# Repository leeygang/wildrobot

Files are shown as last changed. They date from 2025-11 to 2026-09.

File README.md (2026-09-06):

# WildRobot

A humanoid robot locomotion project centered on MuJoCo/JAX training, with an
industry-style RL deployment path as the current mainline for WildRobot.

Current repo reality:
- the repo is pivoting from standing-first PPO exploration toward a
  locomotion-first `v0.19.x` platform
- the deployed runtime artifact remains a **learned policy**
- reduced-order references and IK are moving into top-level `control/` as
  nominal-motion and training-support infrastructure
- `training/` remains the home for RL, eval, export, and locomotion curricula
- `runtime/` remains the hardware-facing layer and will absorb locomotion
  policy running plus shared logging
- `tools/` becomes the explicit home for SysID, replay, and sim2real analysis
- OCS2 / `wb_humanoid_mpc` and URDF migration remain long-term reference
  directions, not the active implementation target for current hardware

Architecture references:
- [docs/system_architecture.md](docs/system_architecture.md)
- [training/docs/walking_training.md](training/docs/walking_training.md) - active locomotion roadmap
- [training/docs/toddlerbot_direct_ppo.md](training/docs/toddlerbot_direct_ppo.md) - `v0.21.0-tb1` direct-PPO parity baseline
- [training/docs/ToddlerBot_direction.md](training/docs/ToddlerBot_direction.md) - ToddlerBot-style pivot rationale
- [training/docs/standing_training.md](training/docs/standing_training.md) - standing branch history and regression gates
- [training/docs/footstep_planner_rl_adoption.md](training/docs/footstep_planner_rl_adoption.md)
- [training/docs/ocs2_humanoid_mpc_adoption.md](training/docs/ocs2_humanoid_mpc_adoption.md)

## Project Structure

Mainline platform split after the locomotion pivot:

```
wildrobot/
├── README.md                           # This file
├── AGENTS.md                           # Agent guidelines
├── CLAUDE.md                           # Claude AI guidelines
├── pyproject.toml                      # Python package configuration (uv)
├── docs/                               # Repo-level architecture and process docs
│   ├── system_architecture.md          # Mainline system architecture
│   ├── URDF_migration_plan.md          # Deferred URDF migration notes
│   ├── e2e_training_to_sim2real.md     # Sim2real flow notes
│   └── sim2real_policy_contract.md     # Policy contract docs
│
├── assets/                             # Digital twin and robot model files
│   ├── v2/                             # Active WildRobot asset variant
│   │   ├── wildrobot.xml               # Main MuJoCo robot model
│   │   ├── mujoco_robot_config.json    # Generated robot metadata
│   │   ├── scene_flat_terrain.xml      # Training scene
│   │   ├── sensors.xml                 # Sensor definitions
│   │   └── assets/                     # Generated Mesh files (STL)
│   ├── post_process.py                 # Post-process during model generation
│   ├── update_xml.sh                   # Regenerate XML/config from Onshape
│   └── robot_config.py                 # Robot config helpers
│
├── control/                            # Reduced-order references, IK, adapters, reusable non-PPO helpers
│   ├── interfaces.py                   # Shared controller / reference-side interfaces
│   ├── robot_model/                    # Robot-model interfaces and conventions
│   ├── reduced_model/                  # LIPM / DCM / ALIP-style helpers
│   ├── references/                     # Walking reference generators (Milestone 2+)
│   ├── kinematics/                     # Leg IK and nominal-motion utilities (Milestone 2+)
│   ├── locomotion/                     # Unified walking controller (v0.19.5)
│   │   ├── __init__.py
│   │   ├── walking_controller.py       # Orchestrator: ref → IK → [optional residual] → ctrl
│   │   │                               #   mode: nominal_only (v0.19.4) | residual_ppo (v0.19.5)
│   │   └── nominal_ik_adapter.py       # IK adapter: task-space targets → joint angles (NumPy)
│   ├── adapters/                       # Reference -> joint-target adapters
│   ├── execution/                      # Servo-friendly execution / tracking layer
│   └── mpc/                            # Reserved for future advanced planner work
│
├── training/                           # RL, eval, export, locomotion curricula
│   ├── train.py                        # Training entry point
│   ├── CHANGELOG.md                    # Training version history (v0.20.1+)
│   ├── CHANGELOG.archive.md            # Training version history (pre-v0.20.1)
│   │
│   ├── cal/                            # v0.11.0: Control Abstraction Layer (CAL)
│   │   ├── __init__.py                 # Export CAL, specs, types
│   │   ├── cal.py                      # ControlAbstractionLayer class
│   │   ├── specs.py                    # JointSpec, ActuatorSpec, Pose3D, Velocity3D
│   │   ├── types.py                    # ActuatorType, VelocityProfile, CoordinateFrame
│   │   └── cal.md                      # CAL documentation
│   │
│   ├── configs/                        # Configuration system
│   │   ├── __init__.py
│   │   ├── training_config.py          # Training config schema
│   │   ├── training_runtime_config.py  # Runtime config
│   │   ├── ppo_walking_v0201_smoke.yaml # v0.20.1 walking smoke
│   │   └── ppo_standing.yaml           # Standing task config
│   │
│   ├── docs/                           # Training documentation
│   │   ├── walking_training.md         # Active locomotion roadmap
│   │   ├── ToddlerBot_direction.md     # ToddlerBot-style pivot note
│   │   ├── standing_training.md        # Standing branch history / regression gates
│   │   ├── footstep_planner_rl_adoption.md # RL-first + optional teacher plan
│   │   ├── ocs2_humanoid_mpc_adoption.md # Deferred OCS2 / humanoid MPC notes
│   │   └── archive/                    # Archived / superseded training docs
│   │       └── learn_first_plan.md     # Historical walking-first roadmap
│   │
│   ├── envs/                           # Environment implementation
│   │   ├── wildrobot_env.py            # Main JAX environment
│   │   ├── env_info.py                 # Typed info + metrics schema
│   │   └── disturbance.py              # Push disturbance utilities
│   │
│   ├── exports/                        # Export utilities
│   │   ├── export_onnx.py              # Checkpoint → ONNX
│   │   ├── export_policy_bundle.py     # Bundle writer (library)
│   │   └── export_policy_bundle_cli.py # Bundle export CLI
│   │
│   ├── eval/                           # Evaluation tools
│   │   ├── eval_policy.py              # Headless evaluation
│   │   ├── eval_ladder_v0170.py        # Standing fixed ladder
│   │   └── visualize_policy.py         # MuJoCo viewer playback
│   │
│   ├── scripts/                        # Analysis scripts
│   │
│   ├── sim_adapter/                    # Sim signal extraction
│   │   ├── mjx_signals.py              # MJX Signals adapter
│   │   └── mujoco_signals.py           # Native MuJoCo Signals adapter
│   │
│   ├── core/                           # Training infrastructure (loop/rollout/metrics)
│   │   ├── __init__.py
│   │   ├── training_loop.py            # Main training loop
│   │   ├── rollout.py                  # Rollout collection
│   │   ├── checkpoint.py               # Checkpoint save/load
│   │   ├── metrics_registry.py         # Metrics tracking
│   │   └── experiment_tracking.py      # W&B integration
│   │
│   ├── algos/                          # Algorithm components
│   │   └── ppo/                         # PPO-specific core
│   │       ├── __init__.py
│   │       └── ppo_core.py              # PPO networks/losses/GAE
│   │
│   ├── tests/                          # All tests (consolidated)
│   │   ├── TEST_STRATEGY.md            # Comprehensive test strategy
│   │   ├── conftest.py                 # Shared test fixtures
│   │   ├── robot_schema.py             # Schema validation utilities
│   │   ├── run_validation.py           # Validation runner
│   │   │
│   │   │ # Physics & Environment Tests
│   │   ├── test_physics_validation.py  # Physics correctness
│   │   ├── test_reward_components.py   # Reward computation
│   │   ├── test_foot_contacts.py       # Contact force validation
│   │   ├── test_env_info_schema.py     # Environment info schema
│   │   │
│   │   │ # Training Component Tests
│   │   ├── test_training_components.py # Training infrastructure
│   │   ├── test_trainer_invariance.py  # Training invariance
│   │   ├── test_ppo_core.py            # PPO algorithm tests
│   │   │
│   │   │ # Math Utility Tests
│   │   ├── test_quat_edges.py          # Quaternion edge cases
│   │   ├── test_quat_normalize.py      # Quaternion normalization
│   │   │
│   │   │ # Environment State Tests
│   │   ├── envs/                       # JAX environment tests
│   │   │   ├── test_jax_env_fns.py
│   │   │   ├── test_jax_equiv_small.py
│   │   │   ├── test_jax_equiv_expanded.py
│   │   │   ├── test_jax_fullstate_small.py
│   │   │   ├── test_jax_contact_equiv.py
│   │   │   └── test_termination_checks.py
│   │   │
│   │   └── debug_contact_forces.ipynb  # Contact force debugging
│   │
│   ├── scripts/                        # Debug & diagnostic scripts
│   │   ├── diagnose_torque.py
│   │   ├── gait_diagnostic.py
│   │   └── test_actuator_range.py
│   │
│   ├── checkpoints/                    # Saved model checkpoints
│   │   └── wildrobot_ppo_*/            # Training run checkpoints
│   │
│   └── wandb/                          # W&B experiment logs
│
├── policy_contract/                    # Shared sim2real contract (spec + JAX/NumPy implementations)
│   ├── spec.py                         # PolicySpec schema + validators + bundle loader
│   ├── spec_builder.py                 # Canonical PolicySpec builder (used by training + export + eval)
│   ├── jax/                            # JAX backend (training)
│   └── numpy/                          # NumPy backend (runtime + tooling)
│
├── runtime/                            # Hardware runtime and shared execution logs
│   ├── README.md                       # Runtime install + run instructions
│   ├── configs/                        # Runtime JSON config templates (hardware calibration source of truth)
│   │   ├── hardware_config.json        # Canonical calibrated hardware config
│   │   ├── walking_v0194.json          # Nominal-only walking deploy config (v0.19.4)
│   │   └── walking_v0195.json          # Residual PPO walking deploy config (v0.19.5)
│   ├── scripts/                        # Calibration tools (IMU/servo/footswitch)
│   └── wr_runtime/                     # Importable runtime package + CLIs
│       ├── control/
│       │   ├── run_policy.py           # Standing/general policy runner
│       │   ├── run_walking.py          # Walking controller entry point (v0.19.5)
│       │   ├── loc_ref_runtime.py      # Walking ref v1 runtime wrapper
│       │   └── loc_ref_runtime_v2.py   # Walking ref v2 runtime wrapper (v0.19.5)
│       └── locomotion/                 # Planned locomotion runner / command / log schema layer
│
├── tools/                              # Sim2real and platform tooling (Milestone 0+)
│   ├── sysid/                          # Actuator characterization and fitting tools
│   └── sim2real_eval/                  # Replay, comparison, and regression plotting tools
│
├── mujoco-brax/                        # Legacy mujoco brax training version.(reference only not used)
│   ├── README.md
│   ├── common/                         # Shared utilities
│   ├── playground/                     # Experimental code
│   └── runtime/                        # Runtime utilities
│
├── isaac/                              # IsaacLab integration (WIP, not used)
│   ├── isaac_lab_strategy.md           # Integration strategy
│   ├── assets/                         # USD assets
│   └── scripts/                        # Conversion scripts
│
└── scripts/                            # Project-level scripts
    ├── scp_to_remote.sh                # Upload to remote server
    └── scp_from_remote.sh              # Download from remote server
```

## Architecture Split

Use this rule of thumb:

- `assets/` owns the digital twin
  - MJCF / scene files
  - generated robot metadata
  - sensor and asset definitions

- `control/` owns locomotion priors and reusable nominal-motion logic
  - reduced-order models
  - reference generation
  - IK and adapters
  - execution / tracking helpers
  - optional future planning experiments

- `training/` owns RL and evaluation
  - locomotion and standing experiments
  - training loops
  - fixed eval ladders
  - reward / curriculum work
  - logging and checkpointing
  - exportable learned policies
  - wrappers that call into `control/`

- `runtime/` owns hardware execution
  - runtime configs
  - policy runners
  - hardware-facing calibration scripts
  - shared runtime log schema

- `tools/` owns sim2real engineering support
  - SysID capture / fitting
  - replay and trace comparison
  - calibration and regression utilities

`training/` may depend on `control/`.  
`control/` should not depend on PPO-specific training code.

## Getting Started

### Prerequisites

- Python 3.11+
- [uv](https://github.com/astral-sh/uv) package manager
- MuJoCo 3.x
- JAX with GPU support (optional but recommended)

### Installation

```bash
# Clone the repository
git clone <your-repo-url>
cd wildrobot

# Install dependencies with uv
uv sync

# Or install in development mode
uv pip install -e .
```

### Running Tests

All tests are consolidated under `training/tests/`:

```bash
# Run all tests
uv run pytest training/tests -v

# Run specific test categories
uv run pytest training/tests/test_physics_validation.py -v  # Physics tests
uv run pytest training/tests/test_reward_components.py -v   # Reward tests
uv run pytest training/tests/test_ppo_core.py -v            # PPO tests
uv run pytest training/tests/envs/ -v                        # Environment tests

# Run with coverage
uv run pytest training/tests --cov=training --cov-report=html
```

## Training

The commands below are for the PPO training stack in `training/`.

For CAD/mass/inertia updates that keep a compatible actor shape, use the
actor-only fine-tuning workflow in
[`training/docs/morphology_finetune.md`](training/docs/morphology_finetune.md).
It deliberately starts a fresh critic and optimizer instead of resuming stale
value/optimizer state.

### Walking Task

```bash
# v0.20.1 walking smoke
uv run python training/train.py --config training/configs/ppo_walking_v0201_smoke.yaml

# Resume from checkpoint (file path, not directory)
uv run python training/train.py \
  --config training/configs/ppo_walking_v0201_smoke.yaml \
  --resume training/checkpoints/<job_dir>/checkpoint_<iter>_<steps>.pkl
```

### Configuration

Training is configured via YAML files in `training/configs/`:

- `ppo_walking_v0201_smoke.yaml` - v0.20.1 walking smoke (offline ZMP prior + bounded residual)
- `ppo_standing.yaml` - Standing balance task

Key configuration options:

```yaml
# Training parameters
training:
  num_envs: 4096
  rollout_steps: 32
  num_iterations: 1000
  learning_rate: 3e-4

# Reward weights
reward:
  velocity_tracking: 1.0
  orientation: 0.5
  action_smoothness: 0.1
```

### Monitoring Training

Training progress is logged to [Weights & Biases](https://wandb.ai/):

```bash
# View live training metrics
wandb login
# Then check your W&B dashboard
```

## Visualization

```bash
# Visualize trained policy
uv run python training/eval/visualize_policy.py \
  --checkpoint training/checkpoints/<checkpoint_dir>
```

## Project Goals

- Develop a bipedal humanoid robot capable of robust locomotion
- Achieve stable walking across flat and rough terrains
- Validate simulation accuracy with comprehensive test suite

## Key Features

- **JAX/MJX Acceleration**: Fast parallel simulation with JAX
- **Prior-Guided PPO**: Offline ZMP reference + bounded residual policy
- **Comprehensive Testing**: 10-layer test strategy from schema contracts to integration
- **Schema Contracts**: Prevents silent breakage from XML changes
- **W&B Integration**: Full experiment tracking and visualization

## Development Workflow

1. **Robot Model**: Define/update robot in `assets/v1/wildrobot.xml` (default) or `assets/v2/wildrobot.xml` (variant)
2. **Configuration**: Adjust training params in `training/configs/`
3. **Training**: Run experiments with `training/train.py`
4. **Testing**: Validate with `pytest training/tests/`
5. **Analysis**: Review metrics in W&B dashboard

## Documentation

Detailed documentation is available in `training/docs/`:

- [Walking Training Plan](training/docs/walking_training.md) - v0.20.x locomotion roadmap
- [Reference Design](training/docs/reference_design.md) - Offline ZMP prior + bounded residual contract
- [Test Strategy](training/tests/test_plan.md) - Comprehensive test plan
- [E2E Runbook](docs/e2e_training_to_sim2real.md) - Train → eval → export → sim2real

## Contributing

Feel free to submit issues and enhancement requests!

## License

[Your License Here]

## Acknowledgments

- MuJoCo and MJX teams at DeepMind
- JAX team at Google
- [Any other acknowledgments]

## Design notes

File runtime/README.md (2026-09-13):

# WildRobot Runtime

Lightweight hardware runtime for running WildRobot ONNX policies on Raspberry Ubuntu.

Implementation lives in `runtime/wr_runtime/` (this is what the installed CLIs use).

Breaking change: the legacy modules under `runtime/control`, `runtime/inference`, `runtime/utils`, and `runtime/validation`
were removed. Use the console scripts (`wildrobot-run-policy`, `wildrobot-validate-bundle`, ...) or import from `wr_runtime.*`.

## Latest contract (v0.21.0, `wr_obs_v8_cmd3d`)

The current walking policy is a **home-base residual** policy (smoke9): the
network outputs a residual that is scaled per-joint and added to the walking
base pose, NOT a direct midpoint-range target.  By default the walking base is
the physical home pose; a bundle can carry small walking-only joint offsets
without changing standing/home calibration.  The runtime composes the target as

```
filtered = postprocess(raw_action)                    # action_filter_alpha=0 -> identity
applied   = previous filtered action                  # action_delay_steps=1
delta     = clip(applied, -1, 1) * residual_scale_per_joint
walking_base_q = home_q_rad + residual_base_offset_per_actuator
target_q  = clip(walking_base_q + delta, joint_min, joint_max)
```

These quantities (residual base/scale/offsets, action delay/filter, the 3D
`(vx, vy, wz)` command, and the gait phase clock) are NOT in `policy_spec.json`.
They are frozen at export time into **`runtime_policy_config.json`** inside the
bundle (see `training/exports/runtime_metadata.py`).  The runner refuses to fall
back to the generic `pos_target_rad_v1` midpoint mapping for a v8 bundle, and
fails loudly for unsupported obs layouts or residual bases.

Legacy `action_scale_rad` in hardware configuration is **ignored** for the
v8 contract — per-joint residual scales come from `runtime_policy_config.json`.

## Install (on robot)

From the `wildrobot/` repo root:

```bash
cd runtime

# Create/update the runtime virtualenv from uv.lock
uv sync
```

Alternative (explicit editable install):
```bash
cd runtime
uv venv
uv pip install -e .
```

Why editable (`-e`) matters: it installs the `wildrobot-*` console scripts while still running
your live checked-out source. If you `git pull` frequently on the device, you usually do *not*
need to reinstall (unless dependencies changed — then rerun `uv sync`).

## Configuration

`runtime/configs/hardware_config.json` is the hardware source of truth. Policy
bundles do not contain hardware configuration. `--hardware-config` remains an
explicit override, and `--runtime-config` remains its legacy alias.

Minimal example:

```json
{
  "robot_config_path": "./mujoco_robot_config.json",
  "servo_controller": {
    "type": "hiwonder_ttl_bus",
    "baudrate": 115200,
    "boards": [
      { "name": "left_leg_board", "port": "/dev/serial/by-id/usb-board-left", "servo_ids": [1, 2, 3, 4] },
      { "name": "right_leg_board", "port": "/dev/serial/by-id/usb-board-right", "servo_ids": [5, 6, 7, 8] },
      { "name": "upper_body_board", "port": "/dev/serial/by-id/usb-board-upper", "servo_ids": [40] }
    ],
    "servos": {
      "left_hip_pitch":  { "id": 1, "servo_offset_unit": 0, "motor_unit_direction": 1, "joint_angle_at_servo_center_deg": 0 },
      "left_hip_roll":   { "id": 2, "servo_offset_unit": 0, "motor_unit_direction": 1, "joint_angle_at_servo_center_deg": 0 },
      "left_knee_pitch": { "id": 3, "servo_offset_unit": 0, "motor_unit_direction": 1, "joint_angle_at_servo_center_deg": 0 },
      "left_ankle_pitch": { "id": 4, "servo_offset_unit": 0, "motor_unit_direction": 1, "joint_angle_at_servo_center_deg": 0 },
      "right_hip_pitch": { "id": 5, "servo_offset_unit": 0, "motor_unit_direction": 1, "joint_angle_at_servo_center_deg": 0 },
      "right_hip_roll":  { "id": 6, "servo_offset_unit": 0, "motor_unit_direction": 1, "joint_angle_at_servo_center_deg": 0 },
      "right_knee_pitch":{ "id": 7, "servo_offset_unit": 0, "motor_unit_direction": 1, "joint_angle_at_servo_center_deg": 0 },
      "right_ankle_pitch": { "id": 8, "servo_offset_unit": 0, "motor_unit_direction": 1, "joint_angle_at_servo_center_deg": 0 },
      "waist_yaw": { "id": 40, "servo_offset_unit": 0, "motor_unit_direction": 1, "joint_angle_at_servo_center_deg": 0 }
    }
  },

  "bno085": {
    "transport": "spi",
    "i2c_address": "0x4B",
    "upside_down": false,
    "spi_baudrate": 50000,
    "spi_read_skip_bytes": 2,
    "spi_cs_pin": "D8",
    "spi_int_pin": "D17",
    "spi_reset_pin": "D27",
    "axis_map": ["+X", "+Y", "+Z"]
  },

  "foot_switches": {
    "enabled": true,
    "left_toe": "D5",
    "left_heel": "D6",
    "right_toe": "D13",
    "right_heel": "D19"
  }
}
```

Notes:
- New deployment bundles keep `wildrobot.xml` and `mujoco_robot_config.json` at
  the root; `bundle_manifest.json` selects each policy ONNX/spec pair.
- Policy/model paths do not belong in the canonical `hardware_config.json`.
- **Servo IDs do not come from MJCF**. Servo IDs are physical IDs stored on the servos / controller and should live in your runtime config (`servo_controller.servos.<joint>.id`).
- `servo_controller.boards` assigns each globally unique servo ID to exactly one named USB TTL board. The required roles are `left_leg_board`, `right_leg_board`, and `upper_body_board`; calibration derives their ID sets from joint names. Run `uv run python runtime/scripts/calibrate.py --config runtime/configs/hardware_config.json --calibrate-servo-board` to detect and write the real ports and assignments. The legacy single-board `servo_controller.port` field remains supported.
- `servo_read_schedule.max_cache_age_s` defines feedback freshness limits. Each board worker continuously round-robins all servos assigned to that board; read-group lists are no longer configured.
- `servo_read_schedule.health_poll_interval_s` sets the per-servo interval for
  low-rate temperature, voltage, and torque-enable reads (default `1.0` s,
  `0` disables them). Health reads are staggered and yield to pending writes
  and position-cache deadlines. With the canonical 5/5/7-servo board split,
  this caps health traffic at 15/15/21 request-response transactions per second
  on the three independent buses; it never performs a health sweep in one
  worker iteration.
- `servo_controller.servos.<joint>.servo_offset_unit` is a per-joint calibration offset in **servo units** around the electrical center (500). Values can be positive or negative. Use the calibration script to write these.
- `servo_controller.servos.<joint>.motor_unit_direction` is a per-joint sign (`+1.0` or `-1.0`) to correct mechanical reversals; if a joint moves the wrong way, flip its sign.
- `servo_controller.servos.<joint>.joint_angle_at_servo_center_deg` (optional, default 0) selects the MuJoCo angle represented by conceptual servo center unit 500. The electrical command at that angle is `500 + servo_offset_unit`. Most joints can keep this at 0. The former `joint_angle_at_zero_unit_deg` key remains load-compatible but is serialized using the new name.
- In the current v2 CAD, the left/right shoulder-roll electrical midpoints are
  MuJoCo `-80` / `+80` degrees respectively. Calibration prints these values;
  do not align raw unit 500 to MuJoCo zero for those two joints.
- Policy and hardware configurations use the same native 17-actuator order. Wrist
  servos are not part of locomotion configuration, feedback, or writes.
- Policy runtime uses the raw Hiwonder/HTD TTL bus through the USB debug board. The old Hiwonder LSC controller-board path is legacy diagnostics only.
- `foot_switches` uses Adafruit Blinka `board` pin names (e.g. `D5`).
  Set `foot_switches.enabled` to `false` when the switches are not installed.
  Contact-free standing policies and `wr_obs_v11_cmd3d_proprio` walking
  policies remain usable; runtime reports the signal as unavailable instead of
  treating placeholder zeros as measured open contacts.
  A walking policy whose observation contract includes foot contacts requires
  enabled, working switches. The runtime rejects that policy while the hardware
  configuration disables the switches; placeholder zeros are out-of-distribution
  policy inputs and must not be used as a deployment workaround.

## Run

`wildrobot-run-policy` loads a deployment bundle containing standing and
walking policies. Normal execution stabilizes with the standing policy before
resetting and starting the walking policy.

Flags:
- `--bundle PATH` (required): deployment or legacy policy bundle.
- `--hardware-config PATH`: explicitly override
  `runtime/configs/hardware_config.json`. `--runtime-config` is a legacy alias.
- `--dry-run`: run with mock IO (no servos/IMU/footswitches) — for smoke tests
  and safe validation on a dev machine. Never sleeps.
- `--max-steps N` (default 500), `--log-steps N` (default 20, 0=off).
- `--fall-tilt-deg DEG`: stop control and unload servos when body tilt exceeds
  the limit (default 45 degrees).
- Every run tees stdout/stderr to `_run_policy_logs/` at the repository root.
  `--log PATH` overrides the automatic path; `--log-only PATH` also suppresses
  console output.
- `--telemetry [PATH]`: save aligned per-control-step sensor, policy, command,
  servo position/tracking, temperature, voltage, torque-enable state, bus
  failures, command clipping, timing, and shutdown-unload verification to a
  compressed `.npz`. With no path, the telemetry file is written beside the
  text log using the same filename stem. HTD-45H does not report motor current
  or calibrated torque; its torque-enable flag is not a load measurement.
- `--velocity-cmd vx` or `--velocity-cmd vx,vy,wz` (default: bundle
  `default_velocity_cmd`, e.g. `0.13,0,0` for smoke9 straight walk).
- `--no-realtime`: don't sleep to maintain `control_hz` (hardware only).

Dry run (no hardware) — exercises the full read → obs → predict → compose →
write loop:

```bash
cd runtime
uv run wildrobot-run-policy --bundle bundles/deployment_walk_v0210_ckpt1650_stand_v0222_ckpt90 \
  --dry-run --max-steps 5 --velocity-cmd 0.13,0.0,0.0
```

On the robot, using the calibrated canonical hardware config:

```bash
cd runtime
uv run wildrobot-run-policy \
  --bundle bundles/deployment_walk_v0210_ckpt1650_stand_v0222_ckpt90 \
  --velocity-cmd 0.13,0,0 --confirm-before-walk
```

### Tethered stance-to-walk diagnostic

Use a slack overhead tether as a fall arrest, not as body support. Put the robot
on the floor, keep the emergency stop or servo power cutoff within reach, and do
not hold or reposition it after the standing policy starts. This command keeps
measured-pose preparation, standing stabilization, operator confirmation, and
walking in one process:

```bash
cd runtime
uv run wildrobot-validate-bundle --bundle bundles/<deployment-bundle>

uv run wildrobot-run-policy \
  --bundle bundles/<deployment-bundle> \
  --hardware-config configs/hardware_config.ports_candidate.json \
  --velocity-cmd 0.065,0,0 \
  --max-steps 50 \
  --startup-pose-blend-s 2 \
  --startup-pose-hold-s 5 \
  --startup-command-ramp-s 1 \
  --startup-action-ramp-s 1 \
  --startup-stability-max-tilt-deg 10 \
  --fall-tilt-deg 10 \
  --confirm-before-walk \
  --diagnostic-log-policy \
  --log-steps 1 \
  --telemetry
```

`--max-steps 50` limits the first walking exposure to one second at the current
50 Hz control rate. If the standing phase, transition, contacts, and tracking
errors are healthy, repeat with 100 steps, then 250 steps; do not increase speed
and duration in the same trial. The runtime unloads the servos on completion,
fall cutoff, Ctrl+C, or an exception.

The `.npz` records phase labels, IMU quaternion/gyro, joint position/velocity,
four foot contacts, complete policy observation, raw/applied action, policy
target, actual blended command, previous command aligned to current feedback,
per-joint tracking error, reference phase, command/action ramps, loop timing,
and servo-cache age/read failures. Inspect it with:

```bash
uv run wildrobot-inspect-log \
  --input ../_run_policy_logs/<matching-policy-log>.npz
```

This follows [ToddlerBot](https://arxiv.org/abs/2502.00893)'s single-process
initial-pose-to-policy handoff and its sim-to-real practice of logging
observations and actions for comparison. The
servos do not expose measured joint torque through the current runtime, so
policy-action occupancy and position tracking error are diagnostics, not direct
physical torque measurements. Keep the synchronized side video for displacement,
foot slip, tether interaction, and fall direction that onboard sensors cannot
observe.

## Run a bundle from `training/checkpoints/` (on the WildRobot device)

Assumptions:
- You have the `wildrobot/` repo synced on the WildRobot device.
- The bundle directory exists under `training/checkpoints/` (exported via `training/exports/export_policy_bundle_cli.py`).

Export one deployment bundle from the selected standing and walking
checkpoints. Hardware configuration is intentionally excluded:

```bash
uv run python training/exports/export_policy_bundle_cli.py \
  --walk-checkpoint training/checkpoints/<walking-run>/checkpoint_NNNN.pkl \
  --training-config training/checkpoints/<walking-run>/training_config.yaml \
  --standing-checkpoint training/checkpoints/<standing-run>/checkpoint_NNNN.pkl \
  --standing-training-config training/checkpoints/<standing-run>/training_config.yaml \
  --bundle-path /tmp/wr_bundle
```

From the repo root on the device:
```bash
cd ~/wildrobot/runtime

# (Recommended) sanity-check raw TTL bus reads before starting control loop
uv run python scripts/probe_hiwonder_ttl_timing.py \
  --port /dev/serial/by-id/usb-1a86_USB_Serial-if00-port0 \
  --baudrate 115200 --servo-ids 1,2,3 --mode read --cycles 20

# Validate the bundle is self-consistent (policy_spec + ONNX dims + actuator order).
# Works on non-Linux dev machines too (rpi-gpio is gated to Linux).
uv run wildrobot-validate-bundle --bundle /tmp/wr_bundle

# Dry run first (no hardware) to confirm the loop builds obs + composes targets:
uv run wildrobot-run-policy --bundle /tmp/wr_bundle --dry-run --max-steps 5

# Run the control loop on hardware (Ctrl+C to stop; runtime disables actuators on exit)
uv run wildrobot-run-policy --bundle /tmp/wr_bundle --confirm-before-walk

# Calibrate the canonical hardware configuration using walking or standing order.
uv run python scripts/calibrate.py --bundle /tmp/wr_bundle \
  --config configs/hardware_config.json --policy-role walking --calibrate
```

Notes:
- `wildrobot.xml` and `mujoco_robot_config.json` are shared policy-model
  snapshots. Each `policies/<role>` directory owns its ONNX, `policy_spec.json`,
  and `runtime_policy_config.json`.
- Servo IDs, offsets, board ports, IMU mapping, and GPIO live only in
  `runtime/configs/hardware_config.json`.

The loop runs for `--max-steps` control steps and then exits, disabling
actuators via `robot_io.close()`.  Ctrl+C also stops it and unloads servos.
To copy the newest hardware policy log from `wrdev.local` into the local
repository, run `./scripts/scp_from_remote.sh --latest-policy-log` from the
repository root.

### Stable-only mode

`--stable-only` (alias `--stable_only`) runs a native 17D standing bundle. The
mode always uses a zero velocity command and runs until Ctrl+C. `--max-steps`
applies only to walking and dry-run execution. Historical deployment bundles
whose walking half is still 21D are archival; point directly at a 17D standing
policy directory for standing-only operation.

```bash
cd runtime
uv run wildrobot-run-policy \
  --bundle bundles/<native-17d-standing-policy> \
  --stable-only \
  --log-steps 20
```

Runtime startup must report 17 policy and hardware actuators. A combined
standing/walking deployment is valid only after the walking policy is migrated
and exported as `(937,17)`. No checked-in historical bundle satisfies the full
native contract.

For the paired hardware diagnostic, run the home hold and standing policy from
the same foot placement with:

```bash
cd runtime
uv run python scripts/run_paired_policy_trial.py \
  --session-log ../_run_policy_logs/paired_session.log
```

The runner prompts once before each of three trials. `READY` starts a single
runtime process that blends from measured joint positions to home for two
seconds, holds home for the remainder of `--home-seconds`, resets policy state,
and automatically activates the standing policy without restarting the IMU or
unloading servos. Each trial writes one combined log under `_run_policy_logs`;
`--session-log` additionally captures the wrapper output in one shareable file.
A policy-runtime import preflight runs before any servo is loaded. The runner
rejects startup or motion above 15 degrees and stops policy control after 60
seconds or at 20 degrees of tilt. This continuous preparation-to-policy handoff
matches ToddlerBot's initial-stand control-loop pattern.

To characterize natural-placement home states without running the policy:

```bash
cd runtime
uv run python scripts/run_paired_policy_trial.py --home-characterization
```

This mode defaults to ten operator-confirmed 60-second trials. Reposition the
robot normally before each `READY`; exact foot placement is not expected to
match. Each home log contains 50 Hz runtime-frame IMU, home target, cached joint
readback/error, servo-cache age, and four footswitch observations. Footswitches
are recorded but never gate a trial. Servos unload after every trial, the
15-degree cutoff is retained, and a
`vXXX_ckptYYY_home_characterization_summary_*.log` JSON summary reports pitch,
tilt, drift slope, joint error, sample rate, and contact ratios across trials.

If you see servo cache initialization or position-read failures:
- Confirm the USB TTL debug board is powered and servos have external power.
- Rerun `calibrate.py --calibrate-servo-board` and confirm every board and servo ID is listed once.
- Confirm `servo_controller.boards[*].port` and `servo_controller.baudrate` in `hardware_config.json` match the debug boards (`115200`).
- Try smaller `--servo-ids` lists in `scripts/probe_hiwonder_ttl_timing.py` to isolate bus or servo issues.

## Bundle utilities

Validate a policy bundle against MJCF + ONNX:
```bash
cd runtime
uv run wildrobot-validate-bundle --bundle ../policies/wildrobot_policy_bundle
```

Inspect a signals log (quick health summary):
```bash
uv run wildrobot-inspect-log --input signals_log.npz
```

> Note: `wildrobot-replay-policy` was removed with the v1/v2 walking-ref stack
> and has not been reintroduced.

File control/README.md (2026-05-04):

# Control Stack

This directory is the non-PPO support path for WildRobot.

Ownership:
- `control/` owns non-PPO helper logic
- `training/` owns experiments, PPO baselines, evals, and training integration

Planned subdirectories:
- `robot_model/`
- `reduced_model/`
- `references/`
- `kinematics/`
- `mpc/` (reserved for advanced planning work if needed later)
- `execution/`
- `adapters/`

This directory is intentionally minimal at the architecture-doc stage.

Current mainline implementation starts from the RL-first plan in:
- `docs/system_architecture.md`
- `training/docs/footstep_planner_rl_adoption.md`

Deferred long-term references:
- `training/docs/ocs2_humanoid_mpc_adoption.md`

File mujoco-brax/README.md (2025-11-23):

# WildRobot Project - Recommended Folder Structure

This document describes the complete folder structure for the WildRobot humanoid robotics project, designed for development, training, and deployment.

## Project Overview

```
wildrobot/
├── models/                    # MuJoCo XML models and 3D assets
├── training/                  # RL training pipelines
├── runtime/                   # Hardware deployment code
├── experiments/               # Research experiments
├── tools/                     # Utilities
├── docs/                      # Documentation
├── tests/                     # Unit and integration tests
├── docker/                    # Docker configurations
└── .github/                   # CI/CD workflows
```

---

## 1. `models/` - Simulation Models

MuJoCo MJCF XML models and associated assets.

```
models/
├── wildrobot_v1/              # Current robot model
│   ├── wildrobot.xml          # Main MJCF file
│   ├── scene.xml              # Scene with ground/lighting
│   ├── scene_position.xml     # Scene with position control
│   ├── actuators.xml          # Actuator definitions
│   ├── sensors.xml            # Sensor definitions
│   └── materials.xml          # Visual materials
│
├── wildrobot_v2/              # Future iterations
│
├── assets/                    # Shared assets
│   ├── meshes/                # STL/OBJ mesh files
│   │   ├── pelvis.stl
│   │   ├── femur_left.stl
│   │   ├── tibia_left.stl
│   │   └── ...
│   ├── textures/              # Texture images
│   └── collision/             # Simplified collision meshes
│
└── README.md                  # Model documentation
```

**Purpose**: Version-controlled robot models used for both training (loco-mujoco) and simulation (MuJoCo viewer).

---

## 2. `training/` - RL Training Pipelines

All training-related code, organized by algorithm.

```
training/
├── amp/                       # AMP training (Adversarial Motion Priors)
│   ├── configs/               # Hydra configs
│   │   ├── wildrobot_amp_amass.yaml        # Train with AMASS data
│   │   ├── wildrobot_amp_custom.yaml       # Train with custom data
│   │   └── wildrobot_amp_walk.yaml         # Walking-specific
│   │
│   ├── scripts/               # Training scripts
│   │   ├── train.py           # Main training entry point
│   │   ├── eval.py            # Evaluation script
│   │   ├── export_onnx.py     # Convert PKL → ONNX
│   │   ├── export_pkl.py      # Extract deployment PKL
│   │   ├── visualize.py       # Visualize trained policy
│   │   └── benchmark.py       # Benchmark inference speed
│   │
│   ├── expert_data/           # Expert demonstrations
│   │   ├── wildrobot_walk.npz
│   │   ├── wildrobot_run.npz
│   │   └── README.md          # Data collection process
│   │
│   └── outputs/               # Training outputs (gitignored)
│       └── YYYY-MM-DD/
│           └── HH-MM-SS/
│               ├── AMPJax_saved.pkl
│               ├── main.log
│               ├── .hydra/
│               └── videos/
│
├── ppo/                       # PPO training (pure RL)
│   ├── configs/
│   ├── scripts/
│   └── outputs/
│
├── shared/                    # Shared training utilities
│   ├── observation_builders.py
│   ├── reward_functions.py
│   ├── data_utils.py
│   └── utils.py
│
├── policies/                  # Production-ready policies (curated)
│   ├── wildrobot_walk_v1.pkl
│   ├── wildrobot_walk_v1.onnx
│   ├── wildrobot_run_v1.pkl
│   ├── wildrobot_run_v1.onnx
│   ├── CHANGELOG.md           # Policy versions and performance
│   └── README.md              # Usage instructions
│
└── README.md                  # Training documentation
```

**Key Principles**:
- Training configs live here, NOT in loco-mujoco
- Scripts are wrappers around loco-mujoco training
- Curated policies in `policies/` for deployment
- Raw training outputs in `outputs/` (gitignored)

---

## 3. `runtime/` - Hardware Deployment

Robot control code for embedded hardware (Raspberry Pi, Jetson Nano).

**Based on Open_Duck_Mini_Runtime structure:**

```
runtime/
├── wildrobot_runtime/         # Main Python package
│   ├── __init__.py
│   │
│   ├── hardware/              # Hardware Abstraction Layer (HAL)
│   │   ├── __init__.py
│   │   ├── motor_controller.py    # Abstract motor interface
│   │   ├── dynamixel_controller.py  # Dynamixel implementation
│   │   ├── hiwonder_controller.py   # Hiwonder implementation (optional)
│   │   ├── imu.py                 # IMU driver (BNO085/ICM45686)
│   │   ├── imu_bno085.py          # BNO085 specific
│   │   ├── imu_icm45686.py        # ICM45686 specific
│   │   ├── encoders.py            # Joint encoders
│   │   ├── height_estimator.py    # Height from leg kinematics
│   │   └── feet_contacts.py       # Foot contact sensors
│   │
│   ├── control/               # Control loops
│   │   ├── __init__.py
│   │   ├── policy_runner.py       # Main 50Hz control loop
│   │   ├── observation_builder.py # Build obs from sensors
│   │   ├── action_processor.py    # Process policy actions
│   │   └── safety_monitor.py      # Safety checks and limits
│   │
│   ├── inference/             # Policy inference engines
│   │   ├── __init__.py
│   │   ├── pkl_infer.py           # JAX/PKL inference
│   │   └── onnx_infer.py          # ONNX Runtime inference
│   │
│   ├── utils/                 # Utilities
│   │   ├── __init__.py
│   │   ├── kinematics.py          # Forward/inverse kinematics
│   │   ├── filters.py             # Low-pass, Kalman filters
│   │   ├── config.py              # Config file loading
│   │   └── logging.py             # Logging utilities
│   │
│   └── io/                    # Optional peripherals
│       ├── __init__.py
│       ├── camera.py
│       ├── speaker.py
│       ├── leds.py
│       └── gamepad.py             # Xbox controller input
│
├── scripts/                   # Executable deployment scripts
│   ├── run_policy.py          # Main deployment script
│   ├── run_policy_pkl.py      # Run with PKL model
│   ├── run_policy_onnx.py     # Run with ONNX model
│   │
│   ├── calibrate_joints.py    # Joint offset calibration
│   ├── calibrate_imu.py       # IMU calibration
│   ├── find_offsets.py        # Interactive offset finder
│   │
│   ├── test_motors.py         # Motor diagnostics
│   ├── test_imu.py            # IMU diagnostics
│   ├── test_sensors.py        # All sensors test
│   ├── test_control_loop.py   # Control loop benchmark
│   │
│   ├── benchmark_inference.py # Benchmark policy speed
│   └── emergency_stop.py      # Emergency stop utility
│
├── configs/                   # Hardware configurations
│   ├── wildrobot_jetson.json      # Jetson Nano config
│   ├── wildrobot_pi5.json         # Raspberry Pi 5 config
│   ├── wildrobot_pi4.json         # Raspberry Pi 4 config
│   ├── example_config.json        # Template config
│   └── README.md                  # Config documentation
│
├── tests/                     # Integration tests
│   ├── test_hardware.py
│   ├── test_inference.py
│   ├── test_observation.py
│   ├── test_control_loop.py
│   └── test_safety.py
│
├── setup.py                   # Python package setup
├── pyproject.toml             # Modern Python packaging
├── requirements.txt           # Runtime dependencies
├── requirements-dev.txt       # Development dependencies
└── README.md                  # Deployment guide
```

**Key Design Principles** (from Open_Duck_Mini):
- **Hardware abstraction**: Easy to swap motor controllers
- **Modular**: Each component testable independently
- **Safety-first**: Built-in safety monitors and e-stop
- **50 Hz control loop**: Exact match with training frequency

---

## 4. `experiments/` - Research Experiments

Experimental code and prototypes (not production).

```
experiments/
├── sim/                       # Simulation experiments
│   ├── terrain_adaptation/
│   ├── push_recovery/
│   ├── stairs_climbing/
│   ├── sloped_walking/
│   └── uneven_terrain/
│
├── hardware/                  # Hardware experiments
│   ├── motor_characterization/
│   ├── sensor_fusion/
│   ├── state_estimation/
│   └── system_identification/
│
└── README.md                  # Experiments index
```

---

## 5. `tools/` - Utilities and Tools

Helper scripts and utilities.

```
tools/
├── calibration/
│   ├── camera_calibration.py
│   ├── imu_calibration.py
│   └── motor_calibration.py
│
├── visualization/
│   ├── plot_training.py
│   ├── compare_policies.py
│   ├── visualize_trajectories.py
│   └── plot_sensors.py
│
├── conversion/
│   ├── pkl_to_onnx.py
│   ├── urdf_to_mjcf.py
│   └── stl_optimizer.py
│
└── data/
    ├── process_mocap.py
    ├── create_expert_data.py
    └── validate_dataset.py
```

---

## 6. `docs/` - Documentation

```
docs/
├── hardware/
│   ├── assembly.md            # Step-by-step assembly
│   ├── bom.md                 # Bill of materials
│   ├── wiring.md              # Wiring diagrams
│   ├── motors.md              # Motor specifications
│   ├── sensors.md             # Sensor specifications
│   └── troubleshooting.md     # Hardware issues
│
├── software/
│   ├── setup_development.md   # Dev environment setup
│   ├── setup_robot.md         # Robot software setup (Pi/Jetson)
│   ├── deployment.md          # Deployment guide
│   ├── pkl_vs_onnx.md         # PKL vs ONNX comparison
│   └── troubleshooting.md     # Software issues
│
├── training/
│   ├── amp_training.md        # AMP training guide
│   ├── ppo_training.md        # PPO training guide
│   ├── expert_data.md         # Creating expert data
│   └── hyperparameters.md     # Tuning guide
│
├── api/
│   ├── runtime_api.md         # Runtime API reference
│   └── training_api.md        # Training API reference
│
└── images/                    # Images for documentation
```

---

## 7. `tests/` - Testing

```
tests/
├── models/                    # Model validation
│   ├── test_mjcf_valid.py
│   └── test_model_physics.py
│
├── training/                  # Training pipeline tests
│   ├── test_observation.py
│   ├── test_reward.py
│   └── test_training.py
│
├── runtime/                   # Runtime tests
│   ├── test_hardware.py
│   ├── test_inference.py
│   ├── test_control_loop.py
│   └── test_safety.py
│
└── integration/               # End-to-end tests
    └── test_full_pipeline.py
```

---

## 8. Root Files

```
wildrobot/
├── .gitignore                 # Git ignore patterns
├── .github/
│   └── workflows/
│       ├── test.yml           # Run tests on push
│       └── deploy.yml         # Deploy to robot
│
├── README.md                  # Project overview
├── SETUP.md                   # Quick setup guide
├── CONTRIBUTING.md            # Contribution guidelines
├── LICENSE                    # License file
│
├── setup.py                   # Python package setup (legacy)
├── pyproject.toml             # Modern Python packaging
├── requirements.txt           # All dependencies
│
├── Makefile                   # Common tasks (optional)
└── docker-compose.yml         # Docker setup (optional)
```

---

## Development Workflows

### 1. Model Development

```bash
cd models/wildrobot_v1/
# Edit wildrobot.xml
vim wildrobot.xml

# Test in MuJoCo viewer
python -m mujoco.viewer wildrobot.xml

# Test in loco-mujoco
cd ../../training/amp
python scripts/train.py --config configs/test.yaml
```

### 2. Training Workflow

```bash
cd training/amp/

# Train policy
python scripts/train.py --config configs/wildrobot_amp_amass.yaml

# Visualize result
python scripts/visualize.py --path outputs/2024-11-23/14-30-00/AMPJax_saved.pkl

# Export for deployment
python scripts/export_onnx.py --policy outputs/.../AMPJax_saved.pkl --output wildrobot_v1.onnx

# Copy to policies/ for deployment
cp wildrobot_v1.onnx ../policies/
cp outputs/.../AMPJax_saved.pkl ../policies/wildrobot_v1.pkl
```

### 3. Deployment Workflow

```bash
cd runtime/

# Install on robot
pip install -e .

# Copy policy to robot
scp ../training/policies/wildrobot_v1.onnx robot@wildrobot.local:~/policies/

# SSH to robot
ssh robot@wildrobot.local

# Test hardware
python scripts/test_motors.py
python scripts/test_imu.py

# Calibrate
python scripts/find_offsets.py

# Run policy
python scripts/run_policy.py --policy policies/wildrobot_v1.onnx --config configs/wildrobot_pi5.json
```

---

## Git Workflow

### Branches
- `main` - Stable, tested code (deployable)
- `develop` - Development branch (integration)
- `feature/*` - Feature branches
- `experiment/*` - Experimental branches
- `hotfix/*` - Emergency fixes

### What to Commit ✅

- Models: `models/`
- Training configs: `training/*/configs/`
- Training scripts: `training/*/scripts/`
- Runtime code: `runtime/wildrobot_runtime/`
- Runtime scripts: `runtime/scripts/`
- Documentation: `docs/`
- Tests: `tests/`
- Curated policies: `training/policies/*.onnx` (small, tested policies)

### What NOT to Commit ❌ (.gitignore)

```gitignore
# Training outputs
training/*/outputs/
*.pkl  # Except in training/policies/

# Python
__pycache__/
*.pyc
*.pyo
*.pyd
.Python
*.so
*.egg
*.egg-info/
dist/
build/
.venv/
venv/

# IDEs
.vscode/
.idea/
*.swp
*.swo

# Logs
*.log
logs/

# OS
.DS_Store
Thumbs.db

# Data
*.hdf5
data/raw/
data/processed/

# Temporary
tmp/
temp/
*.tmp
```

---

## Integration with loco-mujoco

Your WildRobot model needs to be accessible to loco-mujoco for training.

### Option 1: Symlink (Recommended for Development)

```bash
# Create symlink from loco-mujoco to your model
ln -s /Users/ygli/projects/wildrobot/models/wildrobot_v1 \
      /Users/ygli/projects/loco-mujoco/loco_mujoco/environments/humanoids/wildrobot
```

**Advantages**: Changes to model immediately reflected in training

### Option 2: Copy (Cleaner)

```bash
# Copy model to loco-mujoco
cp -r models/wildrobot_v1/* \
      /path/to/loco-mujoco/loco_mujoco/environments/humanoids/wildrobot/

# Update when model changes
# (create a Makefile target for this)
```

**Advantages**: Cleaner separation, no symlink dependencies

### Training Integration

```python
# training/amp/scripts/train.py
from loco_mujoco import ImitationFactory
import hydra
from omegaconf import DictConfig

@hydra.main(config_path="../configs", config_name="wildrobot_amp_amass")
def train(cfg: DictConfig):
    # Create environment (uses model from loco-mujoco)
    env = ImitationFactory.make(
        "MjxWildRobot",  # Registered in loco-mujoco
        **cfg.env_params
    )

    # Train...
    # (rest of training code)

if __name__ == "__main__":
    train()
```

---

## Comparison with Open_Duck_Mini

| Aspect | Open_Duck_Mini | WildRobot |
|---|---|---|
| **Model Location** | `mini_bdx/robots/` | `models/` (separate) |
| **Training** | `experiments/` | `training/` (organized by algo) |
| **Runtime** | `Open_Duck_Mini_Runtime` (separate repo) | `runtime/` (same repo) |
| **Policies** | Root `.onnx` files | `training/policies/` |
| **DOFs** | 14 (with head, antennas) | 11 (no head) |
| **Hardware** | Hiwonder servos | Dynamixel (configurable) |
| **Organization** | Two repos (model + runtime) | Single repo (all-in-one) |

**Advantages of WildRobot structure:**
- ✅ Everything in one repo (easier version control)
- ✅ Clear separation of concerns
- ✅ Better organized training pipelines
- ✅ Reusable runtime architecture

---

## Dependencies

### Development Environment (Mac/PC)

```bash
# Python 3.10+
pip install loco-mujoco jax flax wandb hydra-core
pip install mujoco
pip install jax2tf tf2onnx tensorflow onnx onnxruntime
```

### Robot Environment (Raspberry Pi/Jetson)

**Option A: PKL (JAX)**
```bash
pip install numpy jax jaxlib flax
pip install dynamixel-sdk  # Or your motor controller
```

**Option B: ONNX (Lightweight)**
```bash
pip install numpy onnxruntime
pip install dynamixel-sdk  # Or your motor controller
```

---

## Next Steps

1. **Create directory structure** (use the setup script below)
2. **Copy WildRobot MJCF model** to `models/wildrobot_v1/`
3. **Set up training configs** in `training/amp/configs/`
4. **Create runtime package** in `runtime/wildrobot_runtime/`
5. **Write documentation** in `docs/`

See `SETUP.md` for detailed setup instructions.

---

## Quick Setup Script

```bash
# Run this in /Users/ygli/projects/wildrobot/

# Create directory structure
mkdir -p models/wildrobot_v1 models/assets/{meshes,textures,collision}
mkdir -p training/{amp,ppo,shared,policies}/{configs,scripts,outputs}
mkdir -p runtime/{wildrobot_runtime/{hardware,control,inference,utils,io},scripts,configs,tests}
mkdir -p experiments/{sim,hardware}
mkdir -p tools/{calibration,visualization,conversion,data}
mkdir -p docs/{hardware,software,training,api,images}
mkdir -p tests/{models,training,runtime,integration}
mkdir -p .github/workflows
mkdir -p docker/{training,deployment}

echo "✓ Directory structure created!"
```

---

## Summary

This structure provides:
- **Clear organization** for models, training, and deployment
- **Separation of concerns** (sim vs hardware)
- **Reusable patterns** from Open_Duck_Mini
- **Scalability** for future robot versions
- **Professional layout** for collaboration

Start with this structure and adapt as your project evolves!

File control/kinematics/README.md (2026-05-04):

# Kinematics (Milestone 0)

This directory provides bounded nominal IK utilities for the locomotion stack.

Milestone `v0.19.2` includes:

- `leg_ik.py`: simple sagittal 2-link leg IK with reach clipping and reachability reporting

Deferred:

- full 3D whole-leg IK
- yaw/frontal-plane coupling
- optimization-based IK variants

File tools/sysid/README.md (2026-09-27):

# tools/sysid

`v0.19.1` adds a usable capture path for representative joint SysID traces.

## HTD-45H automatic known-load capture

Use `runtime/scripts/capture_servo_sysid.py` for real HTD-45H
characterization. It runs a single isolated fixture servo through symmetric 2, 5,
and 8 degree steps followed by 0.1-2 Hz decaying chirps at the deployment rate
of 50 Hz. The profile follows ToddlerBot's multi-amplitude chirp method, with a
smaller initial range and bandwidth because the first WildRobot measurement is
on an uncharacterized high-torque servo and lever fixture.

The validated BAM fixture has a fixed top/servo body and a 0.612761 kg moving
arm/weight subtree. Its zero pose hangs nearly vertically, so the default
profile reaches about 0.10 Nm rather than the maximum horizontal gravity load.

The physical fixture must have:

- only the test servo connected to the selected TTL adapter;
- a rigidly mounted servo housing matching `assets/bam/robot.xml`;
- verified collision-free travel across the complete commanded range;
- a catcher that supports the lever and mass whenever torque is disabled; and
- a reachable power cutoff. Never use a hand as the stop or catcher.

Mount the lever so its hanging zero pose matches MJCF `pitch=0`. The first run
uses the exported fixture mass and inertia directly. The fixture servo is
addressed in raw centered coordinates: electrical unit 500 is 0 degrees and
increasing electrical units are positive.

First assign the isolated fixture servo its reserved ID. Without `--set-unit`,
this command does not move or unload the servo. Broadcast discovery requires
that every other servo be physically disconnected from the selected TTL bus:

```bash
uv run python runtime/scripts/set_sysid_servo_id.py \
  --board-port /dev/serial/by-id/usb-1a86_USB_Single_Serial_5C4C127022-if00 \
  --servo-id 100
```

The tool scans all servo addresses, prints the current ID, aborts if more than
one distinct ID responds, requires explicit confirmation, writes the requested
ID, and verifies both the old and new addresses. Two servos already sharing the
same ID cannot be distinguished by the HTD addressed protocol, so the fixture
servo should still be the only servo physically connected.

To position a bare replacement servo at its raw electrical center before
installing the horn, keep the shaft mechanically clear and add `--set-unit
500`:

```bash
uv run python runtime/scripts/set_sysid_servo_id.py \
  --board-port /dev/serial/by-id/usb-1a86_USB_Single_Serial_5C4C127022-if00 \
  --servo-id 100 \
  --set-unit 500
```

`--set-unit` accepts an inclusive raw position from 0 through 1000. The tool
prints the current encoder unit, primes that position before enabling torque,
moves at 20 degrees/s, and verifies the final position within five raw units.
It then holds the target with torque enabled until the operator types `y` to
unload. Ctrl-C or another exception also executes the torque-off cleanup. Do
not use an endpoint target with an installed linkage unless its full travel has
been mechanically verified.

With that servo connected, validate the capture configuration:

```bash
uv run python runtime/scripts/capture_servo_sysid.py \
  --servo-id 100 \
  --board-port /dev/serial/by-id/usb-1a86_USB_Single_Serial_5C4C127022-if00 \
  --center-deg 0 \
  --fixture-mjcf assets/bam/robot.xml \
  --fixture-joint pitch \
  --fixture-direction 1 \
  --fixture-qpos-offset-deg 0 \
  --write-deadband-units 0 \
  --cooldown-target-c 35 \
  --servo-label htd45h-sysid-id100 \
  --fixture-label bam-v1 \
  --dry-run
```

Use `--fixture-direction -1` instead if increasing raw servo angle moves
opposite to positive MJCF `pitch`. Remove `--dry-run` only
after checking the printed root, moving body, moving mass, inertia, torque,
port, and duration. The script then:

1. prints a cancellable startup delay before opening the bus or applying torque;
2. reads the unpowered starting position and torque state, unloads the servo,
   and waits until its temperature reaches `--cooldown-target-c`;
3. records every cooldown temperature, voltage, and actual wait interval;
4. primes the target at the current position, enables torque, verifies it, and
   monitors a loaded hold before issuing any movement;
5. moves to center at a bounded speed while continuously sampling position,
   torque-enable state, voltage, and temperature; it records whether torque was
   lost during the pre-move hold, center movement, or center settle and retries
   automatically up to `--center-max-attempts`; a retry re-primes and reloads a
   servo that disabled torque, then uses a longer move;
6. runs the full profile while checking encoder reads, tracking error, and loop
   timing; voltage, temperature, and torque-enable reads are staggered across
   a bounded extra bus-read budget and abort the profile on a safety violation;
7. returns to center, reads voltage and temperature again, moves to the
   configured gravity-neutral unload pose, verifies it, and disables torque;
8. stops and unloads the servo in a `finally` path on completion, error, or
   Ctrl-C.

Use `--write-deadband-units 0` for the actuator-model identification captures;
this preserves every quantized command. Use a separate run with the deployment
value `3` to measure the combined actuator plus runtime command-suppression
behavior. Each load center remains a separate capture so the operator can
verify the clear travel range and catcher before higher-torque tests. The
campaign runner below invokes those captures sequentially without removing
their cooldown, diagnostics, or safety checks.

Each condition is one invocation so the fixture cannot be reconfigured while
the servo is energized. Review the hanging-zero capture before running
off-vertical centers such as 30 or 45 degrees. Those positions provide greater
gravity load without adding weight. Manual mass/radius arguments remain
available for fixtures without a validated MJCF, but they cannot be combined
with `--fixture-mjcf`.

The output pair is written under `runtime/calibration/servo_sysid/` by default:

- `.npz`: the established `command_rad`, `measured_position_rad`,
  `measured_velocity_rad_s`, and `timestamps_s` arrays, plus raw servo units,
  the smooth `requested_command_rad`, segment labels, command/read timing, and
  `fixture_qpos_rad`, MuJoCo-derived holding torque and moving-load inertia.
  `command_rad` is the quantized target actually transmitted after the
  selected write deadband. Schema v5 also records scheduled and Unix wall time,
  scheduler sleep, actual serial-write completion, command age at each read,
  cooldown temperature/voltage history, and event-oriented `profile_health_*`
  voltage, temperature, and torque-enable samples. `preparation_*` arrays
  preserve the monitored pre-move, start-pose normalization, center-move,
  center-settle, and unload-pose states even when capture fails before the
  profile starts;
- `.json`: fixture geometry and inertia, servo/bus identity, pre/post voltage
  and temperature, initial/center/final positions, torque-load state, all
  operator/cooldown/preparation/profile/return waits, step 10/50/90% response,
  steady gain, command-update cadence, outcome, and per-chirp correlation lag.

The reported chirp `delay_s` is explicitly a cross-correlation lag that includes
servo response dynamics; it is not a pure serial or actuator transport delay.
The default `--profile-health-poll-hz 6` is a total budget: the three health
fields rotate one at a time, giving about 2 Hz per field without putting a
three-read sweep in the 50 Hz position loop. Use the wall-time channel to align
an external current-supply or load-cell trace with the NPZ.

### Torque-loss preparation diagnostic

If the servo unexpectedly reports `loaded=false`, do not repeat the full
campaign. Power-cycle the fixture, leave the load catcher in place, and run one
slow preparation-only movement:

```bash
uv run python runtime/scripts/capture_servo_sysid.py \
  --servo-id 100 \
  --board-port /dev/serial/by-id/usb-1a86_USB_Single_Serial_5C4C127022-if00 \
  --center-deg 30 \
  --fixture-mjcf assets/bam/robot.xml \
  --fixture-joint pitch \
  --fixture-direction 1 \
  --fixture-qpos-offset-deg 0 \
  --prepare-speed-deg-s 5 \
  --prepare-monitor-hz 25 \
  --pre-move-hold-s 2 \
  --center-max-attempts 1 \
  --prepare-only \
  --servo-label htd45h-sysid-id100 \
  --fixture-label bam-v1
```

This diagnostic first holds the servo at its measured starting position for two
seconds, then moves toward +30 degrees at 5 degrees/s, observes the one-second
center settle, and returns to the gravity-neutral zero pose. It never runs the
step/chirp profile. The JSON reports `first_unload`; the NPZ keeps the complete
25 Hz preparation trace and modeled holding torque. A failure in
`post_load_hold` indicates torque cannot remain enabled before motion;
`center_move` indicates a motion/load transient or obstruction; and
`center_settle` indicates that the final static load cannot be held.

The default voltage safety floor is 9.6 V, matching the HTD-45H vendor working
range. If any preparation sample crosses that floor while torque remains
enabled, the script skips the profile, returns to the neutral unload pose, and
marks the capture failed. Console error and exception messages are yellow on a
color-capable terminal; JSON error strings remain plain text.

The HTD protocol does not report motor current and does not expose a latched
active fault code. `alarm_mask=7` only means all three LED alarm sources are
configured. A brief power-rail collapse may therefore require an oscilloscope
or current-logging supply at the servo connector even when the sampled voltage
looks normal afterward.

### Separated load/speed characterization

Before running chirps, characterize the protection boundary with one factor at
a time:

```bash
uv run python runtime/scripts/run_servo_sysid_campaign.py \
  --plan limits \
  --servo-id 100 \
  --board-port /dev/serial/by-id/usb-1a86_USB_Single_Serial_5C4C127022-if00 \
  --fixture-mjcf assets/bam/robot.xml \
  --fixture-joint pitch \
  --fixture-direction 1 \
  --fixture-qpos-offset-deg 0
```

The limits plan runs preparation-only moves, never the step/chirp profile:

1. load sweep: 10, 20, and 30 degrees, all at 5 degrees/s;
2. speed sweep: the identical 0-to-10-degree path at 20, 50, and 100
   degrees/s; and
3. interaction check: the identical 0-to-30-degree path at 10, 15, and 20
   degrees/s.

Before every condition, the capture normalizes the fixture to the configured
zero-degree unload pose at 5 degrees/s and verifies it. The outbound leg then
uses only that condition's test speed, while every return to zero remains fixed
at 5 degrees/s. This prevents an arbitrary unpowered starting angle or a fast
return from contaminating the requested comparison.

The load cases hold each endpoint for three seconds. The validated BAM model
predicts approximately 0.12, 0.24, and 0.35 Nm of static gravity torque at 10,
20, and 30 degrees. Keeping speed fixed in the first sweep isolates the load
trend; keeping the endpoint and path fixed in the second isolates the
speed/current-transient trend. The third sweep then measures their interaction
at the previously demonstrated 30-degree load.

Every condition uses one test attempt and 50 Hz preparation telemetry. The
JSON records the initial and normalized positions, normalization timing,
outbound test speed, and independent return speed. A voltage or torque-disable
event stops the campaign immediately so a reset servo is never mistaken for a
valid slower retry. Power-cycle the fixture and resume at a named condition
only after inspecting the failed JSON/NPZ pair, for example:

```bash
uv run python runtime/scripts/run_servo_sysid_campaign.py \
  --plan limits \
  --servo-id 100 \
  --board-port /dev/serial/by-id/usb-1a86_USB_Single_Serial_5C4C127022-if00 \
  --start-at S1_speed_10deg_20dps
```

This preserves ToddlerBot's later multi-amplitude/frequency SysID structure,
but adds an explicit load axis because WildRobot uses a different, larger
actuator/fixture system and the measured HTD/TTL path has already crossed its
9.6 V operating floor during motion. Use an oscilloscope or supply-current
logger for sub-20 ms transients; the 50 Hz protocol telemetry cannot prove
that faster events did not occur.

### Standard follow-up campaign

After the separated limits plan passes, run the remaining bandwidth,
signed-load, held-out validation, and repeatability conditions with one
command:

```bash
uv run python runtime/scripts/run_servo_sysid_campaign.py \
  --plan sysid \
  --servo-id 100 \
  --board-port /dev/serial/by-id/usb-1a86_USB_Single_Serial_5C4C127022-if00 \
  --fixture-mjcf assets/bam/robot.xml \
  --fixture-joint pitch \
  --fixture-direction 1 \
  --fixture-qpos-offset-deg 0
```

The runner executes six captures in order: a 2-degree 0.1-10 Hz bandwidth
trace at zero, fit traces at +30 and -30 degrees, held-out validation traces at
+45 and -45 degrees, and a final zero-load repeat. All actuator-model captures
use zero command-write deadband. Each child capture normalizes to zero before
its measured move and returns to zero at 5 degrees/s. It also reads and records
the servo EEPROM angle and voltage limits, temperature limit, position/motor
mode, alarm configuration, and accepted move target. It requires no typed
confirmation: after a cancellable startup delay, it waits unloaded for the
servo to cool to 35 C, runs the profile, returns to the verified zero-degree
gravity-neutral pose, and disables torque. A failure or operator abort stops
the campaign immediately; already completed capture pairs remain under the
campaign directory printed at startup.

After a corrected setup or transient preparation failure, resume in a new
campaign directory without repeating completed conditions:

```bash
uv run python runtime/scripts/run_servo_sysid_campaign.py \
  --plan sysid \
  --servo-id 100 \
  --board-port /dev/serial/by-id/usb-1a86_USB_Single_Serial_5C4C127022-if00 \
  --start-at B1_fit_plus30
```

Use `--dry-run` to validate all six profiles and fixture loads without opening
the serial port.

### Comprehensive next BAM campaign

Use the opt-in `complete` plan for the next characterization pass. One command
first dry-runs every condition, then automatically executes the nine separated
load/speed checks, the six signed-load SysID/validation captures, and a final
loaded profile with the deployment command deadband. Each condition retains an
independent cooldown and automatic neutral-pose return:

```bash
uv run python runtime/scripts/run_servo_sysid_campaign.py \
  --plan complete \
  --servo-id 100 \
  --board-port /dev/serial/by-id/usb-1a86_USB_Single_Serial_5C4C127022-if00 \
  --fixture-mjcf assets/bam/robot.xml \
  --fixture-joint pitch \
  --fixture-direction 1 \
  --fixture-qpos-offset-deg 0 \
  --profile-health-poll-hz 6 \
  --max-static-torque-nm 2.5 \
  --dry-run
```

Inspect the printed travel and torque envelope, then remove `--dry-run` for the
hardware run. The campaign writes `campaign_manifest.json` after every child
capture, including checksums, outcomes, safety summaries, modeled fixture
torque, tracking results, and thermal results. A failed or interrupted run
therefore leaves a usable, auditable partial campaign.

The current `assets/bam/robot.xml` fixture reaches only about `0.56 Nm`; running
the complete plan unchanged improves coverage and telemetry but still cannot
identify the HTD-45H walking-load torque boundary. For that question, install a
mechanically verified higher-load fixture and update its MJCF mass/inertia to
match before dry-running this command. Do not raise `--max-static-torque-nm`
merely to bypass preflight: it is a safety ceiling, not a servo rating.

The servo protocol still cannot report motor current or output torque. Connect
a current-logging supply and, ideally, a load cell during this campaign if
those signals are required; the per-sample Unix timestamps are provided for
alignment. Without those external sensors, no software change can recover the
missing electrical/current measurement after the experiment.

The HTD protocol exposes position, supply voltage, and temperature, but not
motor current or torque. Torque-related parameters therefore require the
known lever mass, radius, and inertia and must be fitted across multiple load
conditions; one unloaded trace is not sufficient to identify torque limits.
The reported fixture inertia excludes the MJCF joint's placeholder `armature`
value so that the later fit does not count an assumed actuator inertia as a
measured mechanical load.

### Offline actuator fit

After collecting one zero-load bandwidth trace and mirrored positive/negative
loaded traces, fit the low-load HTD-45H model locally:

```bash
uv run python tools/sysid/fit_servo_dynamics.py \
  servo_sysid/htd45h_servo_100_20260912_210117.npz \
  servo_sysid/htd45h_servo_100_20260912_210528.npz \
  servo_sysid/htd45h_servo_100_20260912_210813.npz \
  --fixture-mjcf assets/bam/robot.xml
```

The fitter replays the quantized 50 Hz commands in the measured one-DOF
fixture and follows ToddlerBot's combined time/frequency-domain comparison. It
fits effective position gain, damping, friction loss, and a discrete
command-delay choice. Armature and actuator `kv` remain fixed: with the current
fixture, damping and armature are strongly correlated and cannot be separated
reliably. Because this fixture exercises less than 0.5 Nm, the fitter also does
not alter the vendor torque limit or a velocity-dependent torque envelope. Add
`--apply` only after inspecting the generated report; this updates both
`assets/v2/joints_properties.xml` and its generated `assets/v2/wildrobot.xml`
mirror.

The 2026-09-12 A1/B1/B2 fit selected zero extra command-delay samples and
changed the shared nominal model from `kp=21.1`, `damping=0.08516`, and
`frictionloss=0.022275` to `kp=31.902`, `damping=1.10618`, and
`frictionloss=0.324094`. Armature remains `0.024992` and actuator `kv` remains
`0.5`. Mean capture replay RMSE improved from 0.8051 degrees to 0.4386 degrees
(45.5%). This is a low-load nominal fit; torque-limit identification and the
held-out +45-degree validation remain separate gates.

References:

- ToddlerBot paper, system-identification method: https://arxiv.org/abs/2502.00893
- ToddlerBot implementation: `~/projects/toddlerbot/toddlerbot/policies/sysID.py`
  and `~/projects/toddlerbot/toddlerbot/tools/run_sysID.py`
- Rhoban BAM actuator-modeling guide:
  https://github.com/Rhoban/bam/blob/main/docs/identification/actuator_modeling.rst
- HTD/Hiwonder protocol examples: `docs/HTD-45H Serial Bus Servo/`

## Capture commands

Step response:

```bash
uv run python tools/sysid/run_capture.py \
  --mode step \
  --joint-name left_knee_pitch \
  --runtime-config runtime/configs/hardware_config.json \
  --output-dir runtime/logs/sysid
```

Hold response:

```bash
uv run python tools/sysid/run_capture.py \
  --mode hold \
  --joint-name left_knee_pitch \
  --hold-rad 0.15 \
  --output-dir runtime/logs/sysid
```

Chirp response:

```bash
uv run python tools/sysid/run_capture.py \
  --mode chirp \
  --joint-name left_knee_pitch \
  --amplitude-rad 0.2 \
  --chirp-start-hz 0.2 \
  --chirp-end-hz 3.0 \
  --output-dir runtime/logs/sysid
```

By default, this commands real hardware through the configured Hiwonder servo board and records measured readback.

Offline/synthetic fallback is still available for CI/dev:

```bash
uv run python tools/sysid/run_capture.py \
  --capture-source synthetic \
  --mode step \
  --joint-name left_knee_pitch \
  --output-dir runtime/logs/sysid
```

## Outputs

Each run writes:

- `<prefix>_<mode>_<joint>.npz` with arrays:
  - `command_rad`
  - `measured_position_rad`
  - `measured_velocity_rad_s`
  - `timestamps_s`
- `<prefix>_<mode>_<joint>.json` manifest with metadata:
  - joint name
  - mode
  - sample rate
  - runtime config path
  - asset/runtime context

## Notes

- Milestone `v0.19.1` now includes a real measurement loop (`--capture-source hardware`, default) plus structured exports.
- Full parameter fitting/optimization loops remain intentionally deferred to `v0.19.2+`.

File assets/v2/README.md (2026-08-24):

# assets/v2 (WildRobot full body with arms)

This folder is the **v2** robot asset variant (full body with arms). The CAD no
longer exports wrist joints or actuators. Remaining hand/wrist meshes are fixed
directly to each forearm and included in the forearm inertia.

- Onshape document (assembly): `WildRobot`
  - Link: https://cad.onshape.com/documents/ba106cac193c0e2253e1958f/w/3b5db3932a544d9f939ac6a6/e/5c6acb3ff696b03bdf018f3b

## Expected files

- `wildrobot.xml` (MJCF)
- `config.json` (Onshape export config for v2; JSONC)
- `scene_flat_terrain.xml` (training scene; includes `wildrobot.xml`)
- `keyframes.xml` (poses; included by scene)
- `mujoco_robot_config.json` (generated; do not hand-edit)
- `assets/` (meshes; referenced by `wildrobot.xml` compiler `meshdir="assets"`)

## How to (re)generate mujoco_robot_config.json

From repo root:

```bash
cd assets/v2
uv run python ../post_process.py wildrobot.xml
```

This writes `assets/v2/mujoco_robot_config.json` next to the MJCF and (if available) runs a basic validation.

## Actuator dynamics

Nominal servo damping, armature, friction loss, position gains, and torque limits
are defined in `joints_properties.xml`. The Onshape export config applies the
`htd45hServo` class to every actuated joint and merges those properties into
`wildrobot.xml`. Per-joint metadata, including maximum velocity, lives in the
generated `mujoco_robot_config.json`.

## Actuator order (ABI)

The 17-actuator order in `wildrobot.xml` must be deterministic for policy/action index stability.

- Canonical order lives in `assets/v2/actuator_order.txt` (one name per line).
- After Onshape export, run:
  - `python3 ../reorder_actuators.py --xml wildrobot.xml --order actuator_order.txt`
  - then `python3 ../post_process.py wildrobot.xml`

The repo `./assets/update_xml.sh` does this automatically.

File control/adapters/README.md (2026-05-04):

# Adapters (Milestone 0)

This package contains small adapter utilities for locomotion contracts.

For Milestone 0, it only includes schema-level composition helpers and avoids
controller logic.

Milestone `v0.19.2` adds:

- `reference_to_joint_targets.py` to convert locomotion reference + leg IK into bounded nominal `q_ref` targets in actuator order.

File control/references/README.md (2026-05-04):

# Locomotion References (Milestone 0)

This package defines the locomotion-first schema contract introduced in `v0.19.0`.

Milestone 0 scope is intentionally schema-only:
- command space (`forward_speed_mps`, `yaw_rate_rps`)
- reference state container used by training/runtime
- observation contract container (IMU orientation + angular velocity, plus command + reference)
- residual action contract around nominal targets

Milestone `v0.19.2` now adds:

- `walking_ref_v1.py`: forward-only bounded stepping reference
- reduced-order step-placement shaping using LIPM/DCM helpers
- outputs compatible with `LocomotionReferenceState`

Still intentionally deferred to `v0.19.3+`:

- policy integration in env/runtime loops
- yaw reference support
- ALIP upgrade

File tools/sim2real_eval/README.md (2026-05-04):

# tools/sim2real_eval

`v0.19.1` adds a practical replay-comparison CLI for actuator realism checks.

## Compare command

```bash
uv run python tools/sim2real_eval/replay_compare.py \
  --real-log runtime/logs/sysid/real_step_left_knee_pitch.npz \
  --sim-log runtime/logs/sysid/sim_step_left_knee_pitch.npz \
  --output-dir runtime/logs/comparisons \
  --summary-json left_knee_step_summary.json \
  --tag left_knee_step
```

## Outputs

- Summary JSON with mismatch metrics:
  - `delay_s`
  - `overshoot_*`
  - `settling_time_s_real`
  - `steady_state_error_*`
  - `position_rmse_rad`
  - `imu_gyro_rmse_rad_s` (when available)
  - `foot_switch_timing_mismatch_frac` (when available)
- Two PNGs:
  - `<tag>_overlay.png`
  - `<tag>_error.png`

## M1 “close enough” practical gate

Use this as a first pass:

- delay magnitude stays within one control step (about `0.02 s` at `50 Hz`)
- position RMSE is materially below commanded amplitude
- overshoot and steady-state error trends are directionally similar between real and sim

This is an engineering gate for transfer readiness, not final transfer hardening.

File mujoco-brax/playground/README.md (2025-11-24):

# WildRobot RL Training with mujoco_playground

GPU-accelerated RL training for WildRobot using Google DeepMind's mujoco_playground framework.

## Directory Structure

```
wildrobot_playground/
├── wildrobot/              # WildRobot environment package
│   ├── base.py            # Base environment class
│   ├── constants.py       # Robot configuration and constants
│   ├── locomotion.py      # Unified locomotion task
│   └── config_utils.py    # YAML config utilities
├── default.yaml           # Default training config (30M steps)
├── quick.yaml             # Quick testing config (5M steps)
├── production.yaml        # Production config (50M steps)
├── train.py               # Training script with W&B logging
├── export_onnx.py         # Export policy to ONNX
└── deploy.py              # Deploy to hardware
```

## Installation

1. **Install mujoco_playground**:
```bash
cd /Users/ygli/projects/mujoco_playground
uv venv --python 3.11
source .venv/bin/activate
uv pip install -U "jax[cuda12]"  # For GPU support
uv pip install -e ".[all]"
```

2. **Install WildRobot runtime** (for deployment):
```bash
cd /Users/ygli/projects/wildrobot/runtime
pip install -e .
```

## Training

### Using Config Files

Train with default configuration (30M steps, 2048 envs):

```bash
cd /Users/ygli/projects/wildrobot/training/wildrobot_playground
python train.py
```

Use a specific config file:

```bash
# Quick training (5M steps, smaller network, no W&B)
python train.py --config quick.yaml

# Production training (50M steps, large network, full logging)
python train.py --config production.yaml
```

### Available Configs

- **`default.yaml`** - Balanced config (30M steps, 2048 envs, W&B enabled)
- **`quick.yaml`** - Fast prototyping (5M steps, 1024 envs, small network, no W&B)
- **`production.yaml`** - Best performance (50M steps, 4096 envs, large network)

### Command-Line Overrides

Override any config parameter from the command line:

```bash
# Override terrain and timesteps
python train.py --terrain rough --num_timesteps 50000000

# Override multiple parameters
python train.py --config quick.yaml \
  --terrain rough \
  --num_envs 4096 \
  --learning_rate 0.0005 \
  --batch_size 1024

# Enable W&B on quick config
python train.py --config quick.yaml --use_wandb=true
```

### Available Command-Line Flags

All flags override config file values:

**Config**:
- `--config` - Path to YAML config file (default: `default.yaml`)

**Environment**:
- `--terrain` - Terrain type: `flat` or `rough`

**Training**:
- `--num_timesteps` - Total training steps
- `--num_envs` - Parallel environments
- `--seed` - Random seed
- `--episode_length` - Max steps per episode

**PPO**:
- `--batch_size` - Batch size
- `--learning_rate` - Learning rate
- `--entropy_cost` - Entropy bonus

**Rendering**:
- `--render` - Render videos after training (true/false)
- `--num_videos` - Number of videos to render

**Logging**:
- `--use_wandb` - Enable W&B logging (true/false)
- `--wandb_project` - W&B project name

**Checkpointing**:
- `--load_checkpoint` - Path to checkpoint to resume from

### Example Commands

```bash
# Default training
python train.py

# Quick test with custom parameters
python train.py --config quick.yaml --terrain rough

# Production training on rough terrain
python train.py --config production.yaml --terrain rough

# Resume from checkpoint
python train.py --load_checkpoint training/logs/wildrobot_*/checkpoints/10000000
```

## Training Outputs

Training creates a timestamped directory in `training/logs/`:

```
training/logs/wildrobot_locomotion_flat_20251123-143000/
├── checkpoints/
│   ├── config.json        # Training configuration
│   ├── 1000000/           # Checkpoint at 1M steps
│   ├── 2000000/
│   └── ...
├── policy.pkl             # Final trained policy (JAX)
└── rollout_*.mp4          # Evaluation videos
```

## Weights & Biases Integration

Training automatically logs to W&B when enabled:

### Key Metrics Logged

- `train/step` - Current training step
- `train/elapsed_time` - Total training time
- `eval/episode_reward` - Average episode reward
- `eval/episode_length` - Average episode length
- `training/*` - Training metrics (policy loss, value loss, entropy)
- `videos/rollout_*` - Evaluation videos

After training starts, you'll see:
```
W&B initialized: https://wandb.ai/username/wildrobot/runs/xxxxx
```

Disable W&B with `--use_wandb=false`.

## Sim-to-Real Transfer

### 1. Export to ONNX

Convert the trained JAX policy to ONNX for deployment:

```bash
python export_onnx.py \
  --policy training/logs/wildrobot_locomotion_flat_20251123-143000/policy.pkl \
  --output wildrobot_v1.onnx
```

### 2. Deploy to Hardware

Run the policy on Raspberry Pi 5:

```bash
# Test motor communication first
python deploy.py \
  --policy wildrobot_v1.onnx \
  --config runtime/configs/wildrobot_pi5.json \
  --test-motors

# Run the policy
python deploy.py \
  --policy wildrobot_v1.onnx \
  --config runtime/configs/wildrobot_pi5.json \
  --duration 30.0
```

## Environment Design

### Observation Space (58D)

The observation vector matches hardware sensors and includes velocity command:

```python
obs = [
    qpos,           # 11 - Joint positions
    qvel,           # 11 - Joint velocities
    gravity,        # 3  - Gravity vector (from pelvis IMU)
    angvel,         # 3  - Angular velocity
    gyro,           # 9  - Gyro readings (3 IMUs × 3)
    accel,          # 9  - Accelerometer readings (3 IMUs × 3)
    prev_action,    # 11 - Previous action
    velocity_cmd,   # 1  - Commanded forward velocity (0-1 m/s)
]
```

### Action Space (11D)

Direct position control for 11 DOFs:

```python
action = [
    right_hip_pitch, right_hip_roll, right_knee_pitch, right_ankle_pitch, right_foot_roll,
    left_hip_pitch, left_hip_roll, left_knee_pitch, left_ankle_pitch, left_foot_roll,
    waist_yaw
]
```

### Reward Functions

**Unified Locomotion Task** (velocity-conditioned):
- Velocity tracking: Match commanded velocity (0-1 m/s)
- Height reward: Maintain target height (0.45m ± 0.05m)
- Upright reward: Keep gravity vector aligned with z-axis
- Lateral penalty: Minimize sideways drift
- Angular velocity penalty: Minimize wobbling
- Action smoothness: Penalize large actions
- Energy penalty: Encourage efficient movement (scaled by velocity)

The same reward function works for all velocities:
- `velocity_cmd = 0.0` → Standing balance
- `velocity_cmd = 0.5` → Normal walking
- `velocity_cmd = 1.0` → Fast walking

## Troubleshooting

### GPU Issues

If JAX doesn't detect GPU:
```bash
export XLA_FLAGS="--xla_gpu_triton_gemm_any=True"
python -c "import jax; print(jax.default_backend())"  # Should print 'gpu'
```

### Import Errors

Make sure mujoco_playground is in your Python path:
```bash
export PYTHONPATH="/Users/ygli/projects/mujoco_playground:$PYTHONPATH"
```

Or install in development mode:
```bash
cd /Users/ygli/projects/mujoco_playground
pip install -e .
```

## References

- [mujoco_playground](https://github.com/google-deepmind/mujoco_playground)
- [MuJoCo MJX](https://mujoco.readthedocs.io/en/stable/mjx.html)
- [Brax PPO](https://github.com/google/brax)

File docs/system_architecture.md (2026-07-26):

# WildRobot System Architecture

**Status:** ToddlerBot-style locomotion pivot active for `v0.19.x`  
**Last updated:** 2026-04-12

---

## Purpose

This document captures the repo-level architecture decision after the
standing-only exploration and the later ToddlerBot / LeRobot comparison.

The project is pivoting from a standing-first PPO branch toward a
locomotion-first robot-learning platform on current WildRobot v2 hardware.

The repo keeps three layers:
- `runtime/` and `assets/` own the hardware interface and digital twin
- `training/` owns RL, eval, export, and locomotion curricula
- top-level `control/` owns reduced-order models, references, IK, and reusable
  non-PPO helpers

The active mainline for current WildRobot hardware is now:
- **MJCF / MuJoCo remains the main simulation path**
- **the deployed controller remains a learned policy**
- **reference-guided RL becomes the active locomotion recipe**
- **reduced-order reference + IK provide nominal motion, not the final
  controller**
- **sim2real becomes an explicit calibration + SysID + evaluation loop**
- **walking becomes the primary product goal on current hardware**
- **standing remains a regression gate, not the top-level destination**

This is the closest match to the practical industry recipe for this robot class:
- simulator-native RL
- policy deployment to hardware
- structured locomotion priors
- actuator realism and transfer hardening
- explicit sim2real tooling

Active planning docs:
- [walking_training.md](/home/leeygang/projects/wildrobot/training/docs/walking_training.md)
- [ToddlerBot_direction.md](/home/leeygang/projects/wildrobot/training/docs/ToddlerBot_direction.md)
- [standing_training.md](/home/leeygang/projects/wildrobot/training/docs/standing_training.md)
- [footstep_planner_rl_adoption.md](/home/leeygang/projects/wildrobot/training/docs/footstep_planner_rl_adoption.md)
- [open_duck_op3_comparison.md](/home/leeygang/projects/wildrobot/training/docs/open_duck_op3_comparison.md)

Reference tiers for the active branch:

1. **Primary architecture and training reference**
   - ToddlerBot:
     - <https://toddlerbot.github.io/>
     - <https://arxiv.org/abs/2502.00893>
   This defines the mainline recipe shape:
   - digital twin quality
   - actuator realism and SysID
   - structured locomotion prior
   - learned runtime policy

2. **Reduced-order locomotion reference**
   - LIPM / DCM / capture-point
   - ALIP-inspired task-space learning:
     - <https://arxiv.org/abs/2309.15442>
   These define the reference-generator shape:
   - task-space step targets
   - reduced-order balance logic
   - nominal motion prior for RL

3. **Direct RL stack references**
   - MuJoCo Playground:
     - <https://github.com/google-deepmind/mujoco_playground>
   - Unitree RL Lab:
     - <https://github.com/unitreerobotics/unitree_rl_lab>
   These define the training and deployment recipe:
   - simulator-native RL
   - direct policy deployment
   - transfer hardening through training

4. **Infrastructure reference**
   - LeRobot:
     - <https://github.com/huggingface/lerobot>
   This is the reference for:
   - dataset and replay tooling
   - robot interface cleanup
   - reusable train/eval/deploy workflows

Deferred reference docs:
- [ocs2_humanoid_mpc_adoption.md](/home/leeygang/projects/wildrobot/training/docs/ocs2_humanoid_mpc_adoption.md)
- [URDF_migration_plan.md](/home/leeygang/projects/wildrobot/docs/URDF_migration_plan.md)

---

## Why The Architecture Changed

The standing exploration established useful baseline facts:
- quiet standing is learnable on current hardware
- PPO itself is not the main blocker
- the hard part is coordinated locomotion and whole-body recovery

The remaining gap is no longer "can RL stabilize standing?" The remaining gap
is:
- reliable step timing
- task-space foot placement
- trunk and pelvis coordination
- repeatable sim2real transfer for locomotion

Three directions were compared:

1. **Keep escalating free PPO**
   - low confidence after the standing branch already exposed the mechanism gap

2. **Jump to full OCS2 / humanoid MPC**
   - still a poor fit for current hardware:
     - position-controlled hobby servos
     - `50 Hz` runtime
     - thin sensing stack
     - no ankle roll

3. **Follow a ToddlerBot-style structured-learning route**
   - highest confidence on current hardware
   - keeps a learned runtime policy
   - adds a stronger locomotion prior and better sim2real discipline

That leads to the current conclusion:
- keep the learned-policy deployment recipe
- add reduced-order reference generation and IK as nominal-motion tools
- train a residual policy around that nominal motion
- make sim2real an explicit engineering loop rather than a later patch

---

## Current Mainline Architecture

The active mainline is reference-guided RL.

```text
MJCF / MuJoCo simulation
    ->
Calibration and SysID
    ->
Reduced-order walking reference
  (LIPM / DCM / capture-point first, ALIP later if needed)
    ->
IK nominal motion generator
    ->
Residual RL policy
    ->
Joint position targets
    ->
Current runtime / hardware path
```

### Layer 1: Simulation and digital twin

Responsibilities:
- keep `assets/v2/wildrobot.xml` as the main simulation model
- preserve MuJoCo contact tuning and actuator semantics
- provide the state path used by training, eval, and runtime parity checks
- absorb actuator, sensor, and latency realism from SysID work

### Layer 2: Calibration and SysID

Responsibilities:
- identify actuator delay, backlash, frictionloss, armature, and torque limits
- calibrate sensor noise and bias
- provide versioned realism parameters for the digital twin

### Layer 3: Reduced-order reference generation

Responsibilities:
- generate task-space locomotion references from command velocity and robot state
- provide gait phase, foothold targets, pelvis targets, and swing-foot targets
- begin with `LIPM / DCM / capture-point`
- later allow `ALIP` if angular-momentum effects matter enough to justify it

### Layer 4: IK nominal motion generation

Responsibilities:
- map task-space reference targets into nominal joint targets
- keep the nominal motion morphology-aware for WildRobot v2
- provide a clear baseline motion for policy residual learning

### Layer 5: RL training stack

Responsibilities:
- policy optimization
- rollout collection
- curriculum
- fixed evaluation
- exportable runtime-compatible policy contract
- residual correction around the nominal reference path

The deployed artifact remains the policy.

### Layer 6: Evaluation and deployment

Responsibilities:
- fixed locomotion and standing regression ladders
- sim2sim checks
- sim2real replay and mismatch analysis
- policy export and runtime deployment

The artifact being evaluated and deployed stays the policy. Reference and IK
layers are part of the locomotion stack, but they are not treated as a separate
standalone controller product.

---

## Architecture Principles

1. **Learned policy remains the deployed controller**
   - The runtime artifact remains a learned policy that matches the current
     hardware path.

2. **Reference-guided RL replaces reward-first discovery**
   - Reduced-order references and IK narrow the search space.
   - The policy learns robustness and adaptation around a nominal motion.

3. **IK is a nominal-motion tool, not the final controller**
   - IK provides the base posture and step realization.
   - The deployed control contract still centers on the learned policy.

4. **Keep MJCF / MuJoCo as the mainline sim path**
   - Do not force URDF or a new simulator into the active branch.

5. **Follow the existing industry recipe**
   - simulator-native RL
   - policy deployment
   - domain randomization / latency / noise hardening
   - structured locomotion prior
   - explicit sim2real tooling

6. **Keep heavyweight model-based stacks as long-term references**
   - OCS2, `wb_humanoid_mpc`, OpenLoong, and MJPC remain reference material.
   - They are not the immediate implementation contract for current hardware.

---

## What We Reuse From The Current Repo

These parts remain mainline assets:
- `assets/v2/wildrobot.xml`
- `assets/v2/mujoco_robot_config.json`
- current scene files in `assets/v2/`
- `training/envs/`
- `training/core/`
- `training/eval/`
- `runtime/configs/hardware_config.json`
- current export/runtime flow
- the standing regression targets in
  [standing_training.md](/home/leeygang/projects/wildrobot/training/docs/standing_training.md)

These remain baseline comparison lines:
- `v0.14.6` hard-push standing baseline
- `v0.17.1` final PPO standing baseline

These remain references, not mainline dependencies:
- OCS2
- `wb_humanoid_mpc`
- URDF-first migration work

---

## What Stops Being Mainline

These paths stay documented, but they are not the active implementation plan:
- full OCS2 / humanoid MPC adoption on current hardware
- URDF-first migration as the mainline path
- standing-first PPO as the top-level product path
- unrestricted joint-space gait discovery from rewards alone
- mocap-first retargeting as the initial locomotion route
- open-ended reward-family growth as the main solution

---

## Folder Ownership

The controller-assist path should still live in **top-level `control/`**, not
`training/control/`.

Ownership rule:
- `control/` owns planner/teacher/helper logic that is not PPO-specific
- `training/` owns experiments, PPO baselines, evals, exports, and runtime
  integration

Practical boundary:
- `training/` may depend on `control/`
- `control/` should not depend on PPO-specific training code

What belongs in `control/`:
- robot model interfaces
- reduced-order helper logic
- locomotion references
- IK / kinematics helpers
- optional teacher or target generators
- adapters and reusable non-PPO support code
- reserved room for future advanced planner experiments

What stays in `training/`:
- PPO baseline stack
- reward and curriculum experiments
- training configs
- evaluation ladder
- W&B / logging / checkpointing
- policy export and runtime contract
- wrappers that call into `control/`

---

## Expected Repo Shape

```text
docs/
  system_architecture.md
  URDF_migration_plan.md            # deferred / conditional

training/docs/
  walking_training.md
  ToddlerBot_direction.md
  standing_training.md
  footstep_planner_rl_adoption.md
  ocs2_humanoid_mpc_adoption.md     # deferred / reference only

control/
  README.md
  robot_model/
  reduced_model/
  references/
    locomotion_contract.py
  kinematics/
    interfaces.py
  mpc/                              # reserved for future advanced planner work
  execution/
  adapters/
    locomotion_action_adapter.py

runtime/wr_runtime/
  logging/
    locomotion_log_schema.py

tools/
  sysid/
  sim2real_eval/
```

In the active branch, `control/` exists to support training and deployment of
the locomotion policy stack, not to replace it with a heavyweight controller.

---

## Milestone Mapping

### `v0.19.0`
- architecture pivot
- locomotion-first roadmap
- shared observation / action contract

### `v0.19.1`
- actuator SysID
- digital twin realism
- sim2real replay tooling

### `v0.19.2`
- `walking_ref_v1`
- `LIPM / DCM / capture-point` reference
- IK nominal motion path

### `v0.19.3`
- reference-guided walking PPO v1 (failed — ctrl ordering bug)
- forward walk + stop attempt
- residual policy export

### `v0.19.4`
- nominal reference validation (M2.5)
- ctrl ordering fix (`CtrlOrderMapper`)
- DCM COM trajectory
- nominal walking achieved (461 steps, 15 gait cycles)

### `v0.19.5`
- walking PPO v2 — residual policy on validated reference
- balance, lateral stability, foot tracking improvements

### `v0.19.6`
- transfer hardening
- history and delay
- domain randomization expansion

### `v0.19.7`
- in-place yaw
- broader command range
- repeatable zero-shot or near-zero-touch transfer

### `v0.19.8`
- disturbance-aware stepping
- moderate push recovery during standing and slow walking
- optional `ALIP` upgrade if the simpler reference saturates

---

## Actuator Ordering

### Problem

The project has two independent actuator orderings:

- **MuJoCo model order** (from XML): groups joints by body side  
  `left_hip_pitch, left_hip_roll, left_knee_pitch, ..., right_hip_pitch, ...`

- **PolicySpec order** (from `mujoco_robot_config.json`): interleaves L/R pairs  
  `left_hip_pitch, right_hip_pitch, left_hip_roll, right_hip_roll, ...`

If ctrl values are written in the wrong order, each actuator receives the
wrong target — e.g., the knee bend command goes to the hip pitch actuator.
This was the root cause of all v0.19.3+ loc_ref training failures.

### Principle: Single Ctrl-Write API

**All code that writes to actuator ctrl must use `CtrlOrderMapper`.**

There must be exactly one code path for converting PolicySpec-ordered ctrl
arrays into MuJoCo-ordered ctrl arrays.  No inline `mj_data.ctrl[i] = ...`
loops that assume a particular ordering.

This applies to:

- **Env** (JAX/MJX): `env._ctrl_mapper.to_mj_jax(ctrl_policy_order)`
- **Viewer** (MuJoCo C API): `ctrl_mapper.set_ctrl_from_qpos(mj_data)` or
  `ctrl_mapper.set_all_ctrl(mj_data, ctrl_policy_order)`
- **Eval scripts**: same `CtrlOrderMapper` instance

### API: `CtrlOrderMapper`

**Location:** `training/utils/ctrl_order.py`

```python
from training.utils.ctrl_order import CtrlOrderMapper

mapper = CtrlOrderMapper(mj_model, policy_spec.robot.actuator_names)
```

#### JAX path (env, training)

```python
mj_ctrl = mapper.to_mj_jax(ctrl_policy_order)  # jax.Array → jax.Array
data = data.replace(ctrl=mj_ctrl)
```

#### NumPy path (viewer, eval)

```python
mj_ctrl = mapper.to_mj_np(ctrl_policy_order)    # np.ndarray → np.ndarray
mapper.set_all_ctrl(mj_data, ctrl_policy_order)  # write directly to MjData
mapper.set_ctrl_from_qpos(mj_data)               # set ctrl = current qpos
mapper.set_ctrl_by_name(mj_data, "left_knee_pitch", 0.99)  # single actuator
```

#### Properties

```python
mapper.policy_to_mj_order       # np.ndarray: perm[policy_idx] = mj_ctrl_idx
mapper.policy_to_mj_order_jax   # jax.Array: same, for JIT contexts
```

### Internal Ordering Convention

| Array | Ordering | Notes |
|---|---|---|
| `nominal_q_ref` | PolicySpec | IK output, walking reference |
| `_default_joint_qpos` | PolicySpec | Home pose joint values |
| `_idx_*` variables | PolicySpec | `_actuator_name_to_index` indices |
| `_actuator_qpos_addrs` | PolicySpec | But values are MuJoCo qpos addresses (name-based lookup) |
| `action_to_ctrl()` output | PolicySpec | Policy contract operates in PolicySpec order |
| `data.ctrl` | MuJoCo | **Must be permuted before writing** |
| `data.qpos` | MuJoCo | Read via `_actuator_qpos_addrs` (correct) |

### Regression Test

`training/tests/test_actuator_ordering.py` — 5 tests:

1. Permutation validity (unique, covers 0..nu-1)
2. All PolicySpec names exist in MuJoCo model
3. `to_mj_ctrl` maps each value to the correct MuJoCo slot
4. `qpos` read consistency via `_actuator_qpos_addrs`
5. After reset + step, `data.ctrl[mj_id]` matches `nominal_q_ref[policy_idx]`

Run: `JAX_PLATFORMS=cpu uv run python -m pytest training/tests/test_actuator_ordering.py -v`

---

## Decision Record

Mainline decision as of `2026-03-31`:
- **Use a ToddlerBot-style locomotion platform direction on current v2
  hardware**
- **Keep the deployed artifact as a learned policy**
- **Use reduced-order references + IK to provide nominal locomotion**
- **Train residual reference-guided RL rather than free gait discovery**
- **Keep MJCF / MuJoCo as the mainline sim and eval stack**
- **Make SysID and sim2real evaluation part of the mainline architecture**
- **Keep OCS2 / `wb_humanoid_mpc` as long-term references only**

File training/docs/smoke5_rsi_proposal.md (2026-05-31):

# smoke5 — Reference State Initialization (RSI) to break the cold-start forward basin (v2)

Status: **approved for implementation** (2026-05-30). Supersedes the chat-only v1.
Incorporates two external-review findings (full reset-state surface; required
residual-base alignment).

## 1. Problem
WR PPO walking (smoke1–smoke4A) cold-starts into a **march/sway-in-place** reward
optimum: survives, lifts feet (`feet_phase≈0.086`), but `forward_velocity≈0`,
`reward/cmd_forward_velocity_track≈0.004` (dead). The only forward-translation
reward (`cmd_forward_velocity_track`, Gaussian `exp(-α·(v−cmd)²)`, α=562.5) has
**near-zero value and gradient from rest**; every other active term is
direction-blind and satisfied in place. Probe confirmed the in-place basin is a
reward/start-state problem, not the reference lookup (clean `ref_selected_vy=0`
at cmd 0.13).

α/param tuning is ruled out: a from-rest gradient needs `α≲1/cmd²`, but at that α
standing pays `exp(-O(1))` → the smoke1 standing leak. No α gives a from-rest
gradient *and* no standing leak.

## 2. Why RSI (evidence)
TB mirrors WR's reward and **its velocity reward is also dead from rest** (σ=1000,
tighter than WR). TB's resolution is **RSI**: reset onto the *moving* reference
manifold. `~/projects/toddlerbot/.../mjx_env.py:900-909` draws a random reference
frame; `:1174-1190` sets `qvel` from the reference (root lin/ang vel + motor/joint
vel) and the phase at that frame → the robot starts mid-stride at ≈cmd, so the
(dead-from-rest) reward is **live (~1.0) at step 0**.

WR resets **static**: `wildrobot_env.py:3310` `qvel=zeros`, control seeded from
the residual base (`:3327`), all path/history state at frame-0/origin. So WR's
reward is dead at step 0 and the body is off the velocity manifold.

Feasibility: WR's library already exposes the per-frame data RSI needs
(`_lookup_offline_window` return, `~1639-1660`): `q_ref`, `pelvis_pos`/
`pelvis_vel`, per-body `body_pos`/`body_quat`/`body_ang_vel`, `phase_sin/cos`,
foot pos/vel. **Important frame note:** the usable root linear velocity is
**`pelvis_vel`** (world/path frame, ≈ commanded forward) — NOT `body_lin_vel`,
which is stored **root-relative (≈0)** and would seed a stationary robot. Joint
velocity is finite-diffed from `q_ref`. **No library regeneration.** The change
is in the reset path only.

## 3. The full RSI reset-state surface (review finding 1 — REQUIRED)
WR's first step depends on more than physics state. RSI must fast-forward the
**entire** reset state to the drawn frame `f`, consistent with `win@f`:

| field | source @ frame f | why it matters |
|---|---|---|
| `qpos` root height/quat | `body_pos[1]`, `body_quat[1]` (root = free-base body, idx 1; xy kept at origin) | physical pose on the gait manifold |
| `qpos` actuated joints | `q_ref` (`_actuator_qpos_addrs`) | mid-stride joint config |
| `qvel` root linear | **`pelvis_vel`** (NOT `body_lin_vel`, which is root-relative ≈0) | **moving at ≈cmd** (makes reward live) |
| `qvel` root angular | `body_ang_vel[1]` | gait bobbing rate |
| `qvel` actuated joints | finite-diff `q_ref` (`_actuator_dof_addrs`) | legs swinging |
| `loc_ref_offline_step_idx` | `f` | reference advances from f |
| `path_state_path_rot` | frame-f path heading (identity for forward-only) | **feeds step-0 heading correction** (`:3724`) |
| `path_state_torso_pos` | frame-f path position | reference world placement |
| `prev_root_pos/quat` | frame-f root | consistent step-1 finite-diff velocity |
| `prev_left/right_foot_pos` | frame-f foot pos | `feet_air_time` / swing metrics |
| `last_left/right_touchdown_x` | frame-f (last touchdown ≤ f) | `step_length` |
| `init_root_pos_xy`, `init_root_yaw` | frame-f root xy/yaw | `world_x_progress` / `yaw_drift` measured from RSI start |
| `loc_ref_*` gait/phase/stance, `v4_compat` | `win@f` (not `win0`) | obs + first-step gait state |
| proprio / critic history buffers | seed from frame-f bundle if cheap; else zeros | softer (history is past-only) |

Note: smoke5 is forward-only (vy=wz=0), so the reference path is straight →
`path_state_path_rot = identity` is correct at every frame, and the body heading
stays ≈0 → no spurious heading-correction lateral flip. (General/turning RSI would
need the true frame-f path heading.)

## 4. Residual-base alignment (review finding 2 — REQUIRED; the base must be `q_ref`)
smoke4A uses `loc_ref_residual_base: home`. RSI **requires a base that FOLLOWS the
time-varying reference, `q_ref(t)` — NOT a static base** (`home` or `ref_init`).
Measured on the WR library:

- **WR gait amplitude `max|q_ref(t) − q_ref(0)| = 0.913 rad ≫ ±0.25` residual
  bound.** So a *static* base (frame-0 `ref_init`, or `home`) leaves mid-stride
  RSI frames **unreachable** — the policy can only reach `base ± 0.25`, but the
  gait spans 0.91. Measured: with `ref_init`, the step-0 control target is **0.50
  rad off** the RSI body pose. (A first draft shipped `ref_init` — this is the
  bug the reviewer caught.)
- With `loc_ref_residual_base: q_ref`, the control base at the RSI frame `f` is
  `q_ref(f)` (the reset `win` is looked up at `step_idx=f`), so the zero-residual
  target ≈ the RSI body pose (measured mismatch **0.07 rad**, within bound), and
  the base advances with `q_ref(t)` as the episode proceeds → genuinely **on the
  moving manifold** at every step.
- Why not TB's static `first_frame_ref` base? TB can use a static base + RSI only
  because TB's gait amplitude fits its action scale. WR's large-amplitude ZMP gait
  (0.91 rad) does not — so WR needs the q_ref base. (This also means smoke5 is the
  v0.20.1 *prior-guided* paradigm + RSI, not "prior-free + RSI"; q_ref base
  supplies the forward template, RSI supplies the on-manifold start, the residual
  stabilizes.)

So smoke5 sets `loc_ref_residual_base: q_ref` (NOT `home`, NOT static `ref_init`).
Env init raises if `loc_ref_rsi_enabled` is paired with a `home` base; the q_ref
base is verified coherent by the control-vs-body test (§6).

## 5. Implementation plan
- Add `env.loc_ref_rsi_enabled: bool` (default False → bit-identical to smoke4A).
- **Train-only**: `reset(perturb_pose=...)` does RSI; `reset_for_eval` keeps the
  static standstill reset (eval/deploy starts from rest — see §7).
- Draw `f ~ U[0, n_frames)` for the sampled command's bin; build `win@f`.
- Construct qpos/qvel + the §3 fields from `win@f`; align residual base per §4.
- Frame conventions (qvel linear/angular global-vs-local, library velocity frame)
  are **validated by test**, not assumed (§6).

## 6. Correctness gates (tests, TDD)
1. **Velocity-mapping test:** RSI-reset at frame f → measured root velocity ≈
   reference **`pelvis_vel@f`** (the world/path-frame forward velocity ≈ cmd) —
   NOT `body_lin_vel` (root-relative ≈0). Validates the qvel source + frame.
   Shipped check (`test_smoke5_train_reset_starts_moving_forward`): root `qvel[0]`
   = +0.13..+0.20 at random frames (= the bin's vx); eval/smoke4A stay at 0.
2. **State-surface test:** RSI reset sets `step_idx==f`, `init_root_pos_xy`,
   `prev_root_pos`, `loc_ref_offline_step_idx` to frame-f values (not 0/origin).
3. **G6 zero-residual-from-RSI invariant:** a zero-residual rollout from an RSI
   frame reproduces the reference motion (within prior viability) — the cleanest
   end-to-end consistency check.
4. **Off-by-default:** `loc_ref_rsi_enabled=False` → reset byte-identical to
   smoke4A (regression guard).
5. `ref_selected_vy ≈ 0` under RSI forward-only (heading stays consistent).

## 7. Decisive risk: eval/deploy starts from rest — monitored OUT-OF-BAND
RSI bootstraps "continue walking"; G4 eval (and deployment) start from rest at
`eval_velocity_cmd=[0.13,0,0]`. The RSI policy must learn the **rest→walk**
transition too — and train metrics can look good (RSI starts already moving)
while from-rest G4 still fails. **In-training eval is DISABLED** (decision
2026-05-30, to avoid in-flight wall-clock overhead). The rest→walk risk is
instead checked **out-of-band on a saved checkpoint** at the 3–5M early-stop —
the same workflow used for smoke2/3/4, with **no training cost**:
```
uv run python training/eval/eval_policy.py --config <smoke5> --checkpoint <ckpt> --num-steps 1000
# (reset_for_eval → static, from rest; train.py:431).  Or:
uv run python training/eval/visualize_policy.py --config <smoke5> --checkpoint <ckpt> --velocity-cmd 0.13 0 0 ...
```
**Required early-stop check:** run that from-rest eval at ~3–5M. If the RSI
train-side forward is healthy but the from-rest `forward_velocity` ≈ 0, that
isolates the rest→walk gap → add a standing→walk curriculum (separate follow-up).
The authoritative post-training eval (`post_training_enabled=true`) still runs at
the end.

## 8. Experiment design
smoke5 = **smoke4A + RSI only** (isolated), plus the required residual-base
alignment. Config: `ppo_walking_v0210_smoke5_rsi.yaml`. Keep everything else from
smoke4A (1D legacy sampler, `cmd_velocity_track_dim=1`, floor 0.065/max 0.26/
interval 0.065, α=562.5, obs_v8, critic actor+privileged). Early-stop at 3–5M on
`forward_velocity>0` / `reward/cmd_forward_velocity_track≥0.01` / `step_length>0`
/ `world_x_progress>0`.

## 9. Out of scope
- Heading-correction clamp (root-cause #2): secondary; keep `ref_selected_vy/wz`
  logged to monitor.
- Reward-shape forward-progress term: the alternative fix family (reward-side);
  fallback if RSI fails/infeasible.

## 10. Key references
- WR reset: `_make_initial_state` (~3299), `reset` (~2685), `ref_init` qpos build
  (~2745), residual/reset base (~350/363).
- WR per-frame data: `_lookup_offline_window` (~1466, return ~1639).
- TB RSI: `~/projects/toddlerbot/toddlerbot/locomotion/mjx_env.py:900-909, 1174-1190`.
- Base config: `ppo_walking_v0210_smoke4_forward_first.yaml`.

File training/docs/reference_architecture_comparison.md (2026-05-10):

# WR Reference Architecture Plan vs ToddlerBot

**Status:** Active phase tracker for `v0.20.x` TB-alignment work.
**Last updated:** 2026-05-09 (Phase 9A criteria/status challenge).
**Purpose:** order the TB-alignment backlog and document forward-looking
phase specs.  Architecture-level decisions (prior selection, layer
contracts, validation ladder) live in
[`reference_design.md`](reference_design.md).  Project-wide milestones
and training-side G-gates live in
[`walking_training.md`](walking_training.md).

### Closeout pattern (as of 2026-05-08)

Completed-phase closeouts are migrated to CHANGELOG entries; this doc
keeps the **forward-looking spec** plus a **brief closeout pointer**
when the phase has shipped.  Phase 1-6 closeouts (pre-2026-04-26) are
preserved in full here as historical record (no CHANGELOG entries
exist for them).  Phase 7+ closeouts point to CHANGELOG:
- Phase 7 (triangle swing-z, `61234d3`) → CHANGELOG
  `v0.20.1-reference-quality-snapshot` + `v0.20.1-phase12A-and-phase8-paired`
- Phase 8 + 12A (paired, h=0.045 + plantarflex smoothstep) →
  CHANGELOG `v0.20.1-phase12A-and-phase8-paired`
- Phase 9A (operating-vx 0.15 → 0.265 + asymmetric parity-vx) →
  CHANGELOG `v0.20.1-phase9A-operating-vx-shift` +
  `v0.20.1-parity-tool-asymmetric-vx-comparison`
- Phase 10 (closed-loop diagnostic, `cc5e8d3` / `381ab3c`) → CHANGELOG
  (see Phase 10 closeout pointer below)
- Phase 12C (left_hip_roll asymmetric saturation) → effectively
  closed by v20 ankle_roll merge + CAD upper_leg mate fix (CHANGELOG
  `v0.20.1-ankle-roll-realignment`)

All file paths in this doc are repo-relative:
- TB: `projects/toddlerbot/...`
- WR: `projects/wildrobot/...`

## Governing Policy

TB is the default reference architecture.

WR should align to TB on reference design and setup unless there is an
explicit reason not to. A WR-specific divergence is acceptable only when at
least one of these is true:

- it is forced by WR hardware or kinematic limits
- matching TB would materially hurt WR trackability or safety
- matching TB would add significant complexity with no measured parity benefit

If none of those are true, the divergence is alignment backlog.

## Acceptance Rule

The goal is not "WR looks reasonable in isolation." The goal is:

- WR reference quality is on par with or better than TB
- the judgment is driven primarily by architecture, not local tuning
- the comparison is size-aware and robot-limit-aware

Use the parity layers in
[reference_parity_scorecard.md](reference_parity_scorecard.md):

- `P0`: shared geometry gate
- `P1A`: FK-realized nominal gait shape
- `P2`: reference smoothness
- `P1`: free-base zero-residual trackability

Acceptance uses two lenses:

- absolute parity is the sanity floor
- size-normalised parity is the primary reading for "on par or better"

This means a WR change should be credited only when it improves the
load-bearing parity gaps under the normalised view, while not regressing the
absolute floor or violating WR's own promotion gates (`G4`, `G5`),
zero-residual invariant, or pre-smoke open-loop baseline — see `walking_training.md` §"Smoke contract — gates vs
commitments" for the full contract.

### Current Criteria Challenge (2026-05-09, post Phase 9D)

The current evidence supports **PPO unblock**, not a blanket "WR is on
par with TB" claim.

- Phase 9D ships a Froude-similar operating point: `cycle_time = 0.96 s`
  (WR-pendulum-scaled from TB's 0.72 s) + `vx = 0.20 m/s` (preserves
  step_length_per_leg ≈ TB's 0.256).  This closes 2 of 3 normalised
  P1A FAILs (`cadence_froude_norm` 1.252× → 0.934× TB,
  `swing_foot_z_step_per_clearance` 1.185× → 0.825× TB) and brings
  absolute `swing_foot_z_step_max` to within 0.9 mm of the TB
  threshold.  Remaining FAIL: `swing_clearance_per_com_height` 0.839×
  TB, pinned by Phase 12A's foot_step_height survival ceiling — Phase
  8 retry at h=0.05 under the longer cycle is the immediate
  follow-up.  See CHANGELOG `v0.20.1-phase9D-cycle-time-scaling`.
- Layer-3 closed-loop gates are comparative-vs-TB diagnostics, not
  absolute pass/fail gates.  WR outlasts TB at analogous operating
  points (Phase 9D vx=0.20: ~55 ctrl steps vs TB 21-23 at vx=0.15);
  both robots fail position-PD-only walking, so the conclusion is
  "this is a learned-policy problem," not "the prior alone walks."
- Any Phase 9D PPO smoke must use q_ref and eval command at the same
  operating point (`loc_ref_offline_command_vx = eval_velocity_cmd =
  0.20`).  Mismatched q_ref/eval-cmd is a null test; the env builds
  an explicit one-bin library for the configured operating point so
  non-grid values cannot snap to a stale default-grid bin.
- The current smoke7 command randomization is not full ToddlerBot
  multi-command reference conditioning because WR's runtime service
  still serves one fixed q_ref trajectory.  Treat it as TB-inspired
  robustness pressure until command-conditioned q_ref lookup lands.

## Design History

This note supersedes the earlier history-only note
`reference_design_history_tb_vs_wr.md`.

The design history matters because the first comparison pass was too weak:

1. We started with a shared geometry gate:
   - stance foot bottom `z <= 0.003 m`
   - swing foot bottom `z > -0.002 m`
   - `vx in {0.10, 0.15, 0.20, 0.25}`
   - frames `{0, 5, 10, 16, 22, 28, 32, 48, 64}`
2. That first pass showed WR was acceptable at the current in-scope bins
   `vx in {0.10, 0.15}`, but weaker than TB at higher speed.
3. We then built a shared parity harness:
   - TB-side geometry test:
     `projects/toddlerbot/tests/test_walk_reference_geometry.py`
   - WR-side parity script:
     `projects/wildrobot/tools/reference_geometry_parity.py`
4. Review of that first harness found three major problems:
   - it mixed WR planner-side quantities with TB FK-realized quantities
   - it called offline gait-shape statistics "trackability"
   - it was missing most smoothness metrics
5. The current structure fixed that split:
   - `P0` shared geometry
   - `P1A` FK-realized nominal gait shape
   - `P2` smoothness
   - `P1` free-base zero-residual replay

That history leads to the current design rule:

- use TB as the baseline
- measure WR using the same realized quantities wherever possible
- prioritize architecture changes before reward or PPO-side tuning

## Current Gap Summary

Post-Phase-6 state (refreshed parity report at commit `ac51038`,
both WR and TB sides re-run under `cycle_time_s = 0.72`).
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

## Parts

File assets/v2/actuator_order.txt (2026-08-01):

# Canonical actuator order for assets/v2 (full body)
# One actuator/joint name per line.
waist_yaw
left_shoulder_pitch
left_shoulder_roll
left_elbow_pitch
left_hip_pitch
left_hip_roll
left_knee_pitch
left_ankle_pitch
left_ankle_roll
right_shoulder_pitch
right_shoulder_roll
right_elbow_pitch
right_hip_pitch
right_hip_roll
right_knee_pitch
right_ankle_pitch
right_ankle_roll

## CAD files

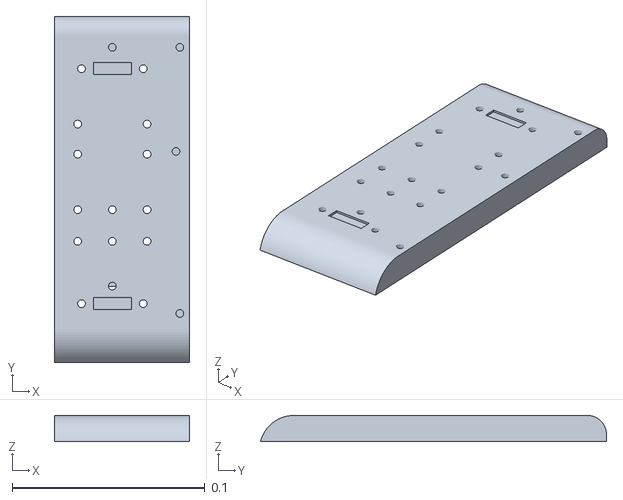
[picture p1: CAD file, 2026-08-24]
assets/v2/assets/foot_main.stl
0.07 x 0.179 x 0.0136

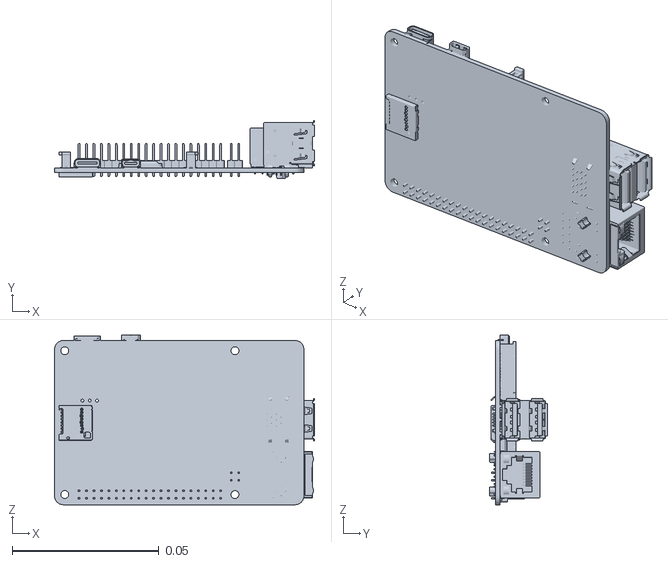
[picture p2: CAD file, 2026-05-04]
assets/v2/onshape_export/assets/rp_assemble.stl
0.0886 x 0.0199 x 0.0578

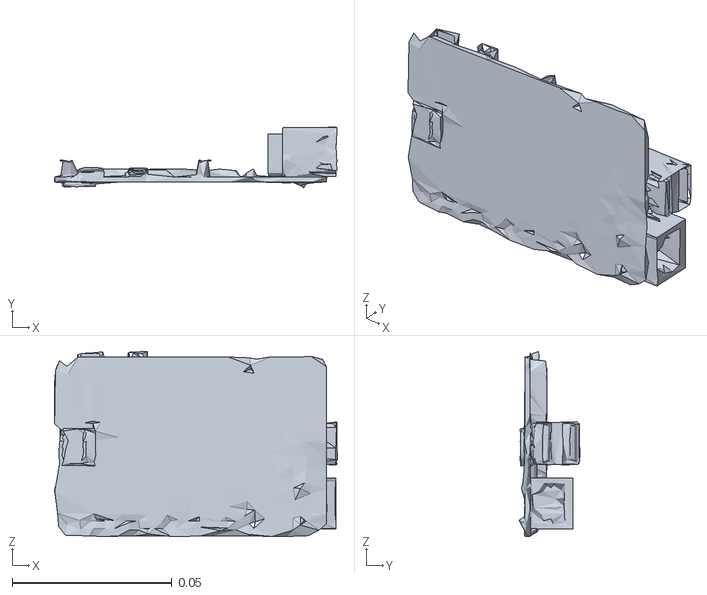
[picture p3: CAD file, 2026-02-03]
assets/v2/assets/rp_assemble.stl
0.0885 x 0.019 x 0.0579

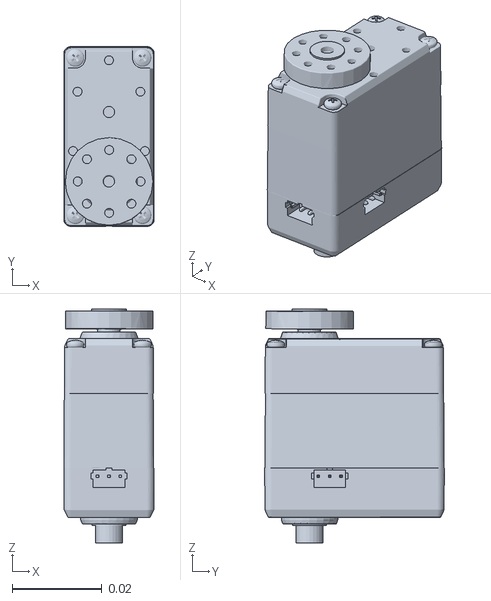
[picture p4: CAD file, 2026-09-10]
assets/bam/assets/htd_45h_1circle.stl
0.0201 x 0.04 x 0.0521

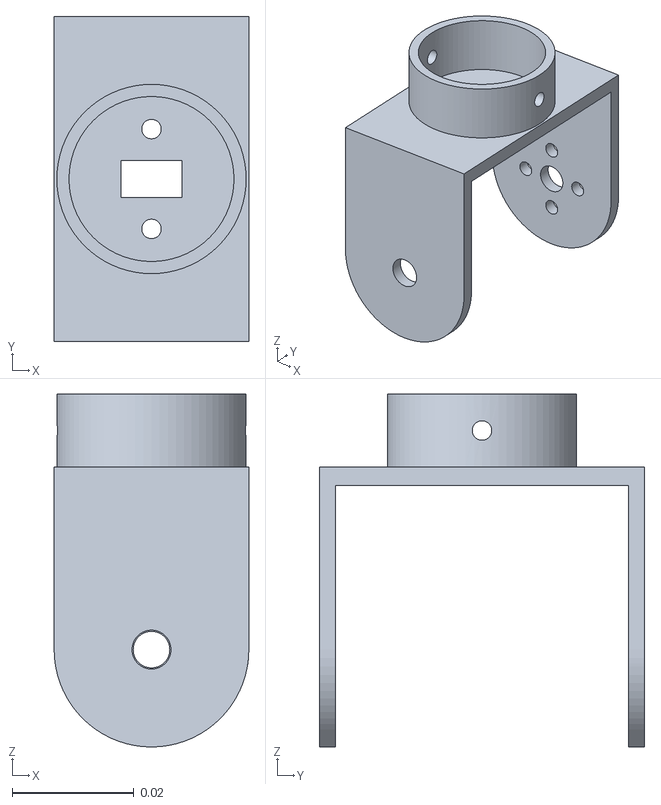
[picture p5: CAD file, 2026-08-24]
assets/v2/assets/albow_servo_bracket.stl
0.032 x 0.0534 x 0.058

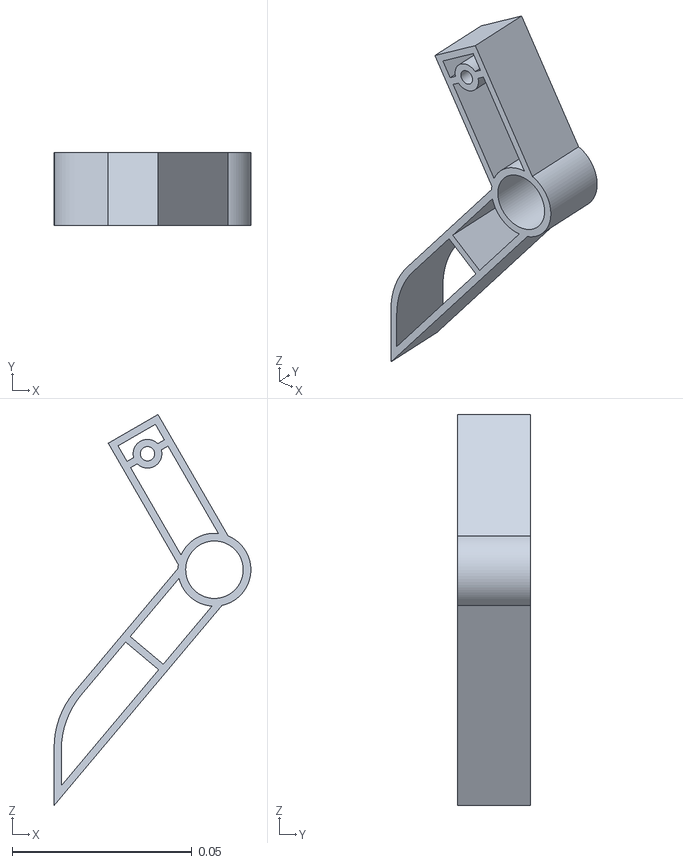
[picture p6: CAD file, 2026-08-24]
assets/v2/onshape_export/assets/finger.stl
0.0548 x 0.0203 x 0.109

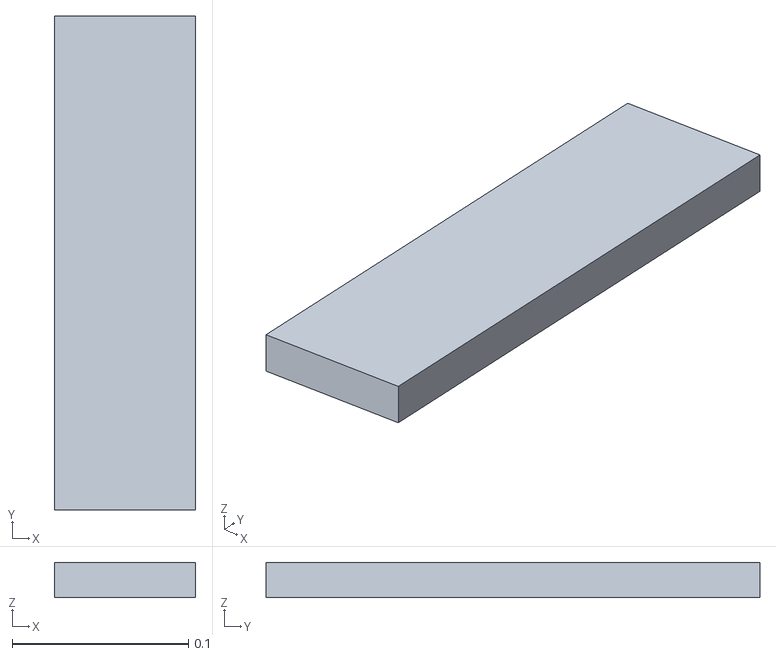
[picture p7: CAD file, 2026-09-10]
assets/bam/assets/fixed_top.stl
0.08 x 0.28 x 0.02

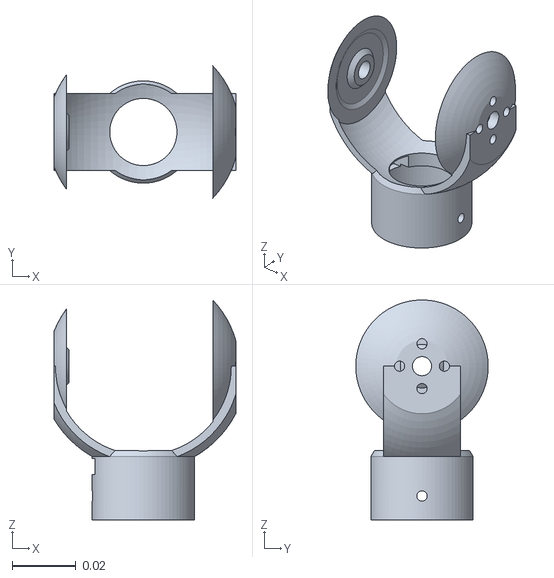
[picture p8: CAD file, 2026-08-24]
assets/v2/assets/shoulder_ball_connector.stl
0.0568 x 0.0414 x 0.0688

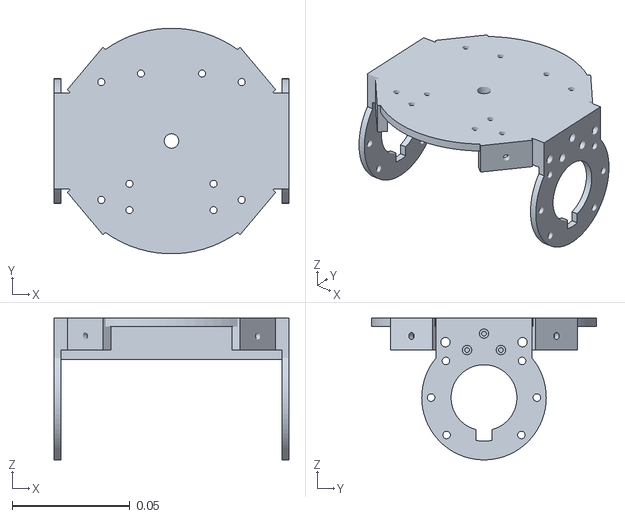
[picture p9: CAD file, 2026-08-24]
assets/v2/onshape_export/assets/trunk_bottom.stl
0.1 x 0.0959 x 0.0603

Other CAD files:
docs/HTD-45H Serial Bus Servo/2. Bus Servo Secondary Development/LSC Series Servo Controller Secondary Develpoment/Controller Secondary Develpoment (51)/output/main.obj
docs/HTD-45H Serial Bus Servo/4. Bus Servo Communication/Serial Bus Servo Control Routine/Rotation Sample/51/main.OBJ
docs/HTD-45H Serial Bus Servo/4. Bus Servo Communication/Serial Bus Servo Control Routine/Wrting Servo ID/51/main.OBJ
docs/HTD-45H Serial Bus Servo/4. Bus Servo Communication/Serial Bus Servo Control Routine/Teaching Record Realization/51/main.OBJ
docs/HTD-45H Serial Bus Servo/4. Bus Servo Communication/Serial Bus Servo Control Routine/Rotation Sample/51/uart.OBJ
docs/HTD-45H Serial Bus Servo/4. Bus Servo Communication/Serial Bus Servo Control Routine/Teaching Record Realization/51/uart.OBJ
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

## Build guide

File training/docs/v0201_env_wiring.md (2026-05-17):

# v0.20.1 Env Wiring Design Note

**Status:** Implemented; supersedes the v5 layout proposal below.
**Scope:** `training/envs/wildrobot_env.py` changes for the v0.20.1 PPO smoke
**Companion docs:** `walking_training.md` (v0.20.1 section), `reference_design.md`

> **Note (high-confidence prep, 2026-04-19):** the active layout is
> `wr_obs_v6_offline_ref_history`, not `wr_obs_v5_offline_ref`.  v6 is
> a strict superset of v5 with a flat 3-frame proprio history appended
> (gyro + foot_switches + joint_pos_norm + joint_vel_norm + prev_action).
> v5 was deprecated and removed from the policy contract; treat all
> `wr_obs_v5_offline_ref` references in this doc as historical context
> for the v6 channel ordering.  See CHANGELOG `v0.20.1-prep`.

This note is the implementation plan for wiring the offline `ReferenceLibrary`
into `WildRobotEnv` so the v0.20.1 smoke (single command `vx=0.15`,
imitation-dominant residual PPO) can run. It replaces the current `walking_ref_v2`
parametric reference path **only inside a new `loc_ref_version=v3_offline_library`
mode**; the existing v1/v2 paths are not touched, so no existing training config
is invalidated by this change.

The design is reviewed before code lands so the surgery on a 2300-line JAX env
is bounded and predictable.

---

## 1. What's already in the env that we keep

The existing residual-action plumbing is reusable as-is. We do not need to write
a new action contract.

- **`_compose_loc_ref_residual_action`** (line 4952): already does
  `residual_delta_q = clip(policy_action, -1, 1) * _residual_q_scale * _joint_half_spans`
  then `target_q = clip(nominal_q_ref + residual_delta_q, joint_mins, joint_maxs)`.
  This IS the action contract `q_target = q_ref_from_library + delta_q_policy`.
- **`_residual_q_scale`** (line 1758): scalar, configurable via
  `loc_ref_residual_scale`.  Currently 0.18 (v0.19.5c default) which gives
  ~±0.18·half_span ≈ ±0.13 rad on a typical leg joint — too small for the
  smoke residual-bounds spec.  See §4 for the change.
- **`_joint_half_spans`** (line 1916): `0.5 * (joint_range_maxs - joint_range_mins)` —
  per-joint span used as the residual scale base.  Reused.
- **`build_observation`** (line 5378): already takes a set of `loc_ref_*` fields
  as kwargs.  Most fields map cleanly to the offline library; a small set
  (the FSM-state fields) become unused in v3.
- **`_apply_startup_support_rate_limiter`** (line 4602): rate-limits big jumps in
  `nominal_q_ref` during the FSM-mode startup ramp.  In v3 the offline library's
  q_ref is already smooth (validated by the FK gate), so this becomes a no-op
  for v3.  Plumb a v3-bypass flag rather than removing.

Update note (2026-05-17):

- The live env has since generalized the residual base selector in
  `training/envs/wildrobot_env.py::_compose_target_q_from_residual`.
- Current supported bases are:
  - `q_ref(t)` for the original smoke7 contract
  - `home_q` for smoke8's TB-aligned direct-base probe
  - `ref_init_q` for smoke9c's constant frame-0 basin probe
- So the statement above remains historically correct for the initial
  v0.20.1 v3 contract, but it is no longer the only active residual form.

## 2. What we replace

**Replace** the parametric reference computation pipeline:

- `step_walking_reference_v2_jax(...)` → `service.lookup_jax(step_idx, jax_arrays)`
- `_compute_nominal_q_ref_from_loc_ref(...)` (line 4720, ~230 lines of IK +
  support-health logic): **fully bypassed** in v3 — `nominal_q_ref` comes
  directly from the offline library's `q_ref` field.  The IK is offline,
  computed once during library generation by `ZMPWalkGenerator`.

**Bypass** (not remove) the FSM-mode plumbing:

- `loc_ref_mode_id`, `loc_ref_mode_time`, `loc_ref_startup_route_*` fields in
  `WildRobotInfo`: keep field declarations (so the existing v1/v2 code paths
  still compile) but set them to fixed sentinel values (e.g., `mode_id=0`,
  `mode_time=0.0`) in v3 reset/step.  Don't read them in the v3 reward branch.

## 3. New runtime state

Three new fields on `WildRobotInfo` (or one composite dict to minimize churn):

| Field | Shape | Purpose |
|---|---|---|
| `loc_ref_offline_step_idx` | `()` int32 | Current step index into the offline trajectory.  Increments by 1 each env step.  Clamped to `n_steps - 1` by the service. |
| `loc_ref_offline_command_id` | `()` int32 | Index into the per-command service registry.  For the smoke this is constant (single command), but the field is included so multi-command future work is forward-compatible. |
| (no field needed) | — | Pre-stacked JAX arrays live on the env object (`self._offline_jax_arrays_by_command`), not in `WildRobotInfo`, because they're constants across env steps. |

Reset writes `loc_ref_offline_step_idx = 0`.  Step increments and clamps via
the service.

## 4. Smoke residual bounds

The current `_residual_q_scale = 0.18` is a single scalar applied to all joints'
half-span.  For the smoke residual-bounds spec (`±0.50 rad` on leg joints,
`±0.20 rad` on others) we need either (a) a per-joint scale array, or (b) a
two-tier scalar split.

**Decision: per-joint scale array.**  Cleanest, doesn't add new config primitives,
and matches how `_joint_half_spans` is already shaped.  Specifically:

- New env config field: `loc_ref_residual_scale_per_joint` (optional dict mapping
  joint name → scalar in [0, 1]).  When present, **overrides** the scalar
  `loc_ref_residual_scale` for those joints; missing joints fall back to the
  scalar.
- For the v0.20.1 smoke, the YAML sets:
  ```yaml
  loc_ref_residual_scale: 0.20         # default (non-leg joints)
  loc_ref_residual_scale_per_joint:
    left_hip_pitch: 0.50
    left_hip_roll: 0.50
    left_knee_pitch: 0.50
    left_ankle_pitch: 0.50
    right_hip_pitch: 0.50
    right_hip_roll: 0.50
    right_knee_pitch: 0.50
    right_ankle_pitch: 0.50
  ```
  These are scaled internally by `_joint_half_spans`, so the actual rad bound
  is `scale * half_span`.  Spec says the smoke residual bound wants `±0.50 rad` directly, NOT
  `±0.50·half_span`.  See §4.1 below.

### 4.1 Scale interpretation: half-span vs absolute

The existing v2 code multiplies `policy_action × scale × half_span`.  For
joints with `half_span > 1.0 rad` (most legs), `scale=0.50` gives `>0.5 rad`
of residual authority — over-shoots the smoke residual-bounds spec.  For joints with
`half_span < 1.0 rad`, it under-shoots.

**Decision: introduce a v3-only `loc_ref_residual_mode` enum**:

- `mode = "half_span"` (current default; preserves v2 behavior; used by v1/v2)
- `mode = "absolute"` (v3 default; `target_q = nominal_q_ref + clip(action, -1, 1) * scale`)

In absolute mode the per-joint `scale` value IS the rad bound directly.  This
matches the smoke residual-bounds spec verbatim and removes a confusing layer of indirection.

The v0.20.1 smoke YAML uses `loc_ref_residual_mode: absolute`.  v1/v2
configurations stay on the existing implicit `half_span` mode (no behavior
change).

## 5. Observation layout — REVISED per round-1 design review

### 5.0 Why `wr_obs_v4` reuse was rejected

The first version of this note proposed reusing `wr_obs_v4` unchanged.
Round-1 review (correctly) flagged this as a blocker: the v0.20.1 smoke
contract (``walking_training.md`` v0.20.1 Observation §) requires the actor
to see a current reference slice that **includes the current `q_ref`**, but
`wr_obs_v4`'s `loc_ref_*` channels (line 5378 of `wildrobot_env.py`) carry
only `phase_sin_cos`, `stance_foot`, `next_foothold`, `swing_pos`,
`swing_vel`, `pelvis_targets`, `history` — **no path for `q_ref`** at all.
Reusing the layout would silently violate the smoke contract.

### 5.1 Decision: new `wr_obs_v5_offline_ref` layout for v3 only

Add a new layout id `wr_obs_v5_offline_ref` that extends `wr_obs_v4` with
the missing channels.  v1/v2 paths keep `wr_obs_v4` (no behavior change for
v0.19.5c).  The smoke YAML sets:

```yaml
env:
  loc_ref_version: v3_offline_library
  actor_obs_layout_id: wr_obs_v5_offline_ref
```

### 5.2 Channels added vs `wr_obs_v4`

| New channel | Shape | Source from `RuntimeReferenceWindow` |
|---|---|---|
| `loc_ref_q_ref` | `[n_joints]` | `window.q_ref` |
| `loc_ref_pelvis_pos` | `[3]` | `window.pelvis_pos` |
| `loc_ref_pelvis_vel` | `[3]` | `window.pelvis_vel` (finite-diff per ref-velocity-sourcing convention) |
| `loc_ref_left_foot_pos` | `[3]` | `window.left_foot_pos` |
| `loc_ref_right_foot_pos`  | `[3]` | `window.right_foot_pos` |
| `loc_ref_left_foot_vel` | `[3]` | `window.left_foot_vel` (finite-diff) |
| `loc_ref_right_foot_vel`  | `[3]` | `window.right_foot_vel` (finite-diff) |
| `loc_ref_contact_mask` | `[2]` | `window.contact_mask` |

This is a strict superset of `wr_obs_v4`'s `loc_ref_*` content: the existing
`v4` channels are still computed and concatenated, and the v5 additions are
appended at the end so that `wr_obs_v4`-shaped consumers (e.g., the
`build_observation` builder) remain compatible if we re-route them.

### 5.3 Channels NOT added (deferred)

Per the smoke obs contract ("do not start the first smoke with a large
dense future preview window"), the following `RuntimeReferenceWindow` fields
are NOT included in `wr_obs_v5_offline_ref`:

- `future_q_ref`, `future_phase_sin/cos`, `future_contact_mask`
  (the 1-2 future anchor frames)

These are reserved for a `wr_obs_v6_*` upgrade if the smoke shows the
policy needs anticipation.  `RuntimeReferenceService` already computes
them; the env just doesn't read them in v5.

### 5.4 Deferred: `loc_ref_pelvis_rpy` channel

The library currently emits `pelvis_rpy = zeros` (yaw-stationary, no
explicit roll/pitch shaping).  The reward (`ref/body_quat_track`) reads
pelvis RPY directly from the trajectory, not via the obs.  **No
`loc_ref_pelvis_rpy` obs channel for v5** — adding it would be a noisy zero
input for the policy.  If a future prior emits non-zero pelvis_rpy targets,
add the channel then.

### 5.5 Implementation surface — REVISED per round-2 review

The previous version of this section understated the code surface.  The
actual observation builders are split across two files (JAX and NumPy
parity is mandatory because `policy_contract` is consumed both at training
time and at export / runtime), and both must accept the new channels and
the new layout id.

**Mandatory dual-builder changes** (these are the round-2 review's
explicitly-named files; both need synchronized edits):

- **`policy_contract/jax/obs.py`**:
  - line 32: extend the layout id whitelist
    `{"wr_obs_v1", "wr_obs_v2", "wr_obs_v3", "wr_obs_v4"}` →
    add `"wr_obs_v5_offline_ref"`
  - line 12 (`build_observation_from_components`): add new kwargs
    `loc_ref_q_ref`, `loc_ref_pelvis_pos`, `loc_ref_pelvis_vel`,
    `loc_ref_left_foot_pos`, `loc_ref_right_foot_pos`,
    `loc_ref_left_foot_vel`, `loc_ref_right_foot_vel`,
    `loc_ref_contact_mask` (each defaulting to `None` with a `zeros(...)`
    fallback identical in pattern to the existing `loc_ref_*` fallbacks)
  - line 94-95 (the per-layout `parts.extend(...)` block): add a new
    branch for `wr_obs_v5_offline_ref` that extends with both the
    `wr_obs_v4` parts (phase, stance, foothold, swing_pos, swing_vel,
    pelvis, history) AND the eight new v5 channels in the order listed
    in §5.2
  - line 102 (`build_observation` wrapper): add the same eight new
    kwargs and forward them to `build_observation_from_components`
- **`policy_contract/numpy/obs.py`**: identical edits (mirror the JAX
  changes line-for-line; the existing parity test will fail if they
  diverge).  The NumPy builder is what the export bundle and runtime
  policy adapter consume.

**Other implementation surface** (orchestration, config, env-side):

- `training/envs/wildrobot_env.py`:
  - `_get_obs` (line 5378 area): when
    `layout_id == "wr_obs_v5_offline_ref"`, read the v3 service window
    and pass the eight new channels to `build_observation`
  - the existing `wr_obs_v4` callsite stays unchanged (it just doesn't
    pass the new kwargs)
- `training/policy_spec_utils.py` (line 130 area): allow
  `actor_obs_layout_id = "wr_obs_v5_offline_ref"`
- `training/configs/training_runtime_config.py` (line 119 area): no
  validation change required (the field is already a free-form string),
  but add a comment noting the v5 layout exists and what mode it pairs
  with
- `training/exports/export_policy_bundle.py`: defer until smoke actually
  ships a checkpoint worth exporting (export bundle just needs to know
  the obs dim — driven by the spec, not hard-coded)

**Parity test obligation**: there is a JAX/NumPy parity test for the
observation builders.  Whatever it asserts for `wr_obs_v4` (concatenation
ordering, dtype, shape) must hold for `wr_obs_v5_offline_ref` too;
the implementer should extend the parity test fixture to include the
new layout id and the new channel set.

**Net change footprint**: 2 builder files (synchronized), 1 env file
(one new branch), 1 spec-utils file (one whitelist entry), 1 config-doc
update, 1 parity-test extension.  No checkpoint format change; existing
`v0.19.5c` configs / checkpoints unaffected because they continue to
use `wr_obs_v4`.

## 6. Reset & step deltas

**Reset (v3 mode only):**

```python
# Existing: build runtime parametric reference state
# v3:        load offline trajectory + build service + write step_idx=0

if loc_ref_version == "v3_offline_library":
    # Service is pre-built at env __init__ (one per command in the smoke set)
    win = self._offline_service.lookup_np(0)  # for reset only — NumPy is fine
    nominal_q_ref = jp.asarray(win.q_ref, dtype=jp.float32)
    # Skip _compute_nominal_q_ref_from_loc_ref entirely.
    # Skip _apply_startup_support_rate_limiter (offline q_ref is already smooth).
    # Use win.* fields to populate the loc_ref_* slots in WildRobotInfo.
    wr_info_extras = dict(loc_ref_offline_step_idx=jp.int32(0), ...)
```

**Step (v3 mode only):**

```python
if loc_ref_version == "v3_offline_library":
    step_idx = wr.loc_ref_offline_step_idx + 1
    win = self._offline_service.lookup_jax(step_idx, self._offline_jax_arrays)
    nominal_q_ref = win["q_ref"]
    # Populate loc_ref_* fields from win for reward + obs.
    # _compose_loc_ref_residual_action used unchanged but with "absolute" residual mode.
```

Both reset and step preserve the existing `WildRobotEnvState` shape — the new
fields are added to `WildRobotInfo` (the dataclass already has spare slots; the
NamedTuple fallback gets new fields too).

## 7. Pre-smoke "zero-action" wiring check — REFINED per round-1 review

The check is **wiring-focused**, not locomotion-quality-focused.  Round-1
review noted that mixing the two would let a balance failure mask a wiring
failure (or vice versa).

Implementation (`tests/test_v0201_env_zero_action.py`):

1. **Wiring assertion (primary)**: with `policy_action = zeros`, the env
   computes `target_q == nominal_q_ref == q_ref_from_library[step_idx]`
   exactly (or within float32 round-off), at every step in a 50-step
   probe.  This is testable without running physics — just call the env's
   action-composition path and inspect `target_q`.
2. **Residual-zero assertion**: `_compose_loc_ref_residual_action`
   returns `residual_delta_q` that is byte-zero when `policy_action = 0`
   (verifies the absolute-mode plumbing in §4.1).
3. **Trajectory-advance assertion**: across 50 steps,
   `wr.loc_ref_offline_step_idx` advances `0, 1, 2, ..., 49`; the
   `loc_ref_*` obs channels read from the service track those step
   indices (not stuck on step 0 due to a missed increment).
4. **PD-trackability probe (informational, NOT a balance test)**: optional
   short physics rollout (≤20 steps) that records `data.qpos -
   q_ref_lib`.  The test does not assert any specific tracking RMSE bound
   — that's the kinematic/fixed-base closeout's job.  We log the value so
   regressions in actuator/PD config show up, but failure to track
   tightly is NOT the wiring test failing.

The test catches: wrong joint ordering, wrong residual mode, q_ref
shifted by one step, missed step-idx increment, FSM-mode plumbing
leaking into the v3 path.  It does NOT catch: balance instability,
reward bugs, learning failures (those are the smoke runner's job).

## 8. Files touched — REVISED (rewrite scope, round-3)

After committing steps 1-3a (config / WR info / dual obs builders / `__init__`
infrastructure), it became clear the original "surgical add v3 branches"
plan was infeasible: ``training/envs/wildrobot_env.py`` is 6533 lines
deeply entangled with several deprecated subsystems beyond v1/v2
(M3 FSM, MPC standing controller, teacher targets, recovery metrics,
v0.19.5c reward family).  Stripping them piecemeal in 6 commits would
leave the env in indeterminate states between commits and risk silent
regressions in the v0.19.5c reward pipeline.

User direction (round-3): **rewrite ``wildrobot_env.py`` from scratch
as a v3-only module**, dropping the deprecated subsystems entirely
rather than carrying them forward through deprecation cycles.  No
backward-compat with v0.19.5c.

**Already deleted** (commit ``0ffc473``):

- ``control/references/walking_ref_v1.py`` (173 lines)
- ``control/references/walking_ref_v2.py`` (1523 lines)
- ``control/references/locomotion_contract.py`` (146 lines)
- ``tests/test_walking_ref_v1.py``, ``tests/test_walking_ref_v2.py``,
  ``tests/test_walking_v0193_integration.py``,
  ``training/tests/test_v0195_walking_controller.py``,
  ``tests/test_runtime_loc_ref_builder.py``

**To delete in the next session** (consequent on the rewrite):

*Source modules and configs:*

| File | Why |
|---|---|
| ``runtime/wr_runtime/control/loc_ref_runtime.py`` | wraps walking_ref_v1 |
| ``runtime/wr_runtime/control/loc_ref_runtime_v2.py`` | wraps walking_ref_v2 |
| ``runtime/wr_runtime/control/run_walking.py`` | uses both |
| ``tools/reference_smoke/`` (whole directory) | v0.19.2 smoke |
| ``training/eval/run_m25_v2_probe_sweep.py`` | M2.5 v2 probe |
| ``training/eval/visualize_nominal_ref.py`` | v1/v2 plotter |
| ``training/eval/eval_loc_ref_probe.py`` | v2 probe runner — emits v2-only summary keys (``debug_loc_ref_swing_x_scale_mean``, ``tracking_loc_ref_progression_permission_mean``, hybrid mode ids, etc.).  The v3 env doesn't compute any of these signals (no v2 hybrid state machine, no swing-x brake heuristic).  A v3 nominal-tracking probe can be re-introduced later if Task #49 needs one — different shape, different metrics. |
| ``control/locomotion/nominal_ik_adapter.py`` | v1/v2 IK adapter |
| ``control/locomotion/walking_controller.py`` | v0.19 walking ctrl |
| ``training/configs/ppo_walking_v0193a.yaml`` | v1-bound |
| ``training/configs/ppo_walking_v0195.yaml`` | v2-bound |
| ``training/configs/ppo_walking_v0195c.yaml`` | v2-bound (kept as design reference; can be archived) |
| ``training/envs/teacher_step_target.py`` | M3 teacher |
| ``training/envs/teacher_whole_body_target.py`` | M3 teacher |

*Tests bound to dropped subsystems* (audited 2026-04-19; many still
import cleanly because the removed names live in the deleted env's
internals, but they will fail at construction or assertion time
because the v3 env no longer offers FSM / MPC / teacher / recovery /
v2 ref state).  Delete in the same cleanup commit as the source modules:

| Test file | Bound to |
|---|---|
| ``tests/test_eval_loc_ref_probe.py`` | v2 probe runner above; asserts v2-specific summary keys |
| ``tests/test_v0171_boundary_push_eval.py`` | v0.17.1 push-recovery scaffold |
| ``tests/test_mpc_standing_v0173.py`` | MPC standing pivot (drop list) |
| ``tests/test_teacher_step_target.py`` | M3 teacher targets (drop list) |
| ``tests/test_fsm_integration.py`` | M3 step FSM (drop list) |
| ``tests/test_recovery_metrics_aggregation.py`` | recovery_* fields + RECOVERY_WINDOW_STEPS constant (already broken: ImportError) |
| ``tests/test_imu_noise_latency.py`` | imports the env's ``_apply_imu_noise_and_delay`` helper; helper survived but the test setup uses v0.19.5c env construction |
| ``training/tests/test_env_step.py`` | v0.19.5c env-step contract |
| ``training/tests/test_env_info_schema.py`` | WildRobotInfo full-schema check (depends on M3/recovery fields that §10 step 4 will drop) |
| ``training/tests/test_physics_validation.py`` | v0.19.5c physics smoke |
| ``training/tests/test_actuator_ordering.py`` | M2.5 ctrl-ordering scaffold (now belongs in policy_contract tests) |
| ``training/tests/test_ppo_training.py`` | v0.19.5c trainer smoke |
| ``training/tests/test_foot_contacts.py`` | v0.19.5c foot-contact aggregation reward |
| ``training/tests/run_validation.py`` | non-pytest smoke runner that constructs v0.19.5c env |
| ``training/scripts/debug_amp_features.py`` | already broken: imports nonexistent ``get_feature_config`` and ``EnvConfig`` from removed modules |
| ``training/scripts/diagnose_amp_features.py`` | AMP-debug coupled to v0.19.5c env metrics |

Tests that **stay** (post-rewrite verified):
``tests/test_policy_contract_parity.py``,
``tests/test_runtime_reference_service.py``,
``tests/test_policy_contract_migration.py`` —
these decoupled from the v0.19.5c env-internal contract.

**To update in the next session** (drop loc_ref builder dependency):

- ``runtime/wr_runtime/control/run_policy.py`` — strip
  ``RuntimeLocRefBuilder`` import; wire to a v3 service when the
  hardware-deployable runtime adapter lands (v0.20.2 milestone)
- ``runtime/wr_runtime/validation/replay_policy.py`` — same

**To rewrite** (the big one):

- ``training/envs/wildrobot_env.py`` — see §10 below for scope

## 9. Open design questions (decide before code)

**Q1.** `loc_ref_pelvis_targets` from offline library has `pelvis_rpy = zeros`
(the prior is yaw-stationary and currently emits zero roll/pitch targets).  Is
that a problem for `m3_pelvis_orientation_tracking`?  
**Proposed answer**: no — the smoke uses the new imitation reward family (Task 3),
not the v0.19.5c m3 family.  The new `ref/body_quat_track` reads pelvis_rpy
from the library directly and rewards small deviation from those zero targets.

**Q2.** What if the policy reaches the end of the 22-second offline trajectory
within an episode?  
**Proposed answer**: per the library's clamp contract, the service freezes at
the terminal frame.  Episode horizon `max_episode_steps = 500` × `ctrl_dt = 0.02`
= 10 s, well under the trajectory's 22 s.  No clamp triggered in normal
operation.  ``RuntimeReferenceService.lookup_np`` emits a one-shot
``RuntimeWarning`` per service instance if a query lands past the end
(added in commit ``<TBD>`` after round-1 review; covered by
``test_terminal_clamp_emits_warning_once``).  The JAX path can't issue
warnings inside JIT, so callers running JAX-only loops must either size the
horizon to ``service.n_steps`` or run a NumPy-side overrun probe out of
band.

**Q3.** Multi-command smoke later — is the per-command service registry
forward-compatible?  
**Revised answer (round-1 review)**: NO, not as originally proposed.  A
Python dict keyed by an integer cannot be indexed inside a JAX JIT'd step
using a JAX-traced integer; the lookup would have to happen outside the
JIT, defeating the per-step efficiency the service is built for.

For the v0.20.1 smoke (single command), the dict-of-services approach is
fine — ``loc_ref_offline_command_id`` is a Python constant (always 0), the
JIT folds it, and the JAX arrays for that one command are threaded through
the step exactly as designed.  This is a **smoke-only simplification**, not
forward-compatible multi-command machinery.

If multi-command training resumes (later milestone), the right design is
**stacked JAX arrays** at the env level:

- ``self._offline_jax_arrays_stacked`` shape ``[n_cmd, n_step, ...]``
  for each field, built once at env init by stacking the per-command
  service outputs
- ``loc_ref_offline_command_id`` is a JAX-traced int, used as the leading
  index in the stacked arrays inside the JIT
- the per-command Python ``RuntimeReferenceService`` instances are kept
  for NumPy-side use (eval, viewer, tests) but the JAX path no longer
  routes through them

That is additive over this design (the service interface doesn't change;
only the env-side storage does).  Explicitly out of scope for v0.20.1.

**Q4.** What about reset RNG?  Should the offline trajectory have a per-env
random start offset (e.g., to avoid all envs walking the same prefix)?  
**Proposed answer**: NOT for the smoke — single-command, single-trajectory,
all envs start at step 0.  This makes the pre-smoke zero-action sanity check
cleanly reproducible.  Random start offsets become useful for multi-command
training; defer.

**Q5.** Per-joint residual scale: should leg joints get directional asymmetry
(e.g., +0.5 rad / -0.3 rad to constrain backward-leaning motions)?  
**Proposed answer**: NOT for the smoke.  Symmetric clip is simpler and lets the
G5 anti-exploit metric do its job (catch the policy when it leans too far).
Asymmetric clipping is a v3.1 lever if needed.

## 10. Implementation sequence — REVISED (rewrite, round-3)

**Status at the session boundary** (commit ``dccca5f``, post §10
steps 1-7 except hardware runtime adapter):

Task #50 (the env rewrite) and §10 cleanup steps 4 + 7 are landed.
Branch is ready for Task #49 (imitation reward family).

Landed commits since the placeholder:
- ``6ee70a2`` — Step 1 audit (``training/docs/v0201_env_rewrite_audit.md``)
- ``3a27a57`` — Steps 3+5: v3-only ``wildrobot_env.py`` (~1200 lines) +
  stub ``ppo_walking_v0201_smoke.yaml`` + register
  ``wr_obs_v5_offline_ref`` layout in ``policy_contract/spec*``
- ``ab261a7`` — review fixes #1-#3: terminal metrics carry through
  auto-reset; live diagnostics (forward_velocity, phase_progress,
  pitch, roll, residual_*); env auto-loads robot_config
- ``9e72fa3`` — review fix #4: ``residual_q_abs_*`` measures the
  applied (post-filter, post-delay) delta, not the raw policy action
- ``482f3b6`` — explicit cleanup list for §10 step 7
- ``957a051`` — Step 7: deleted 5 source modules + 16 stale tests +
  fixed dangling ``control/kinematics/__init__.py`` import
- ``dccca5f`` — Step 4: pruned ``WildRobotInfo`` from ~95 fields to 35

**Validation (CPU backend at ``dccca5f``):**
- 20/20 surviving core tests pass:
  ``tests/test_policy_contract_parity.py`` (7) +
  ``tests/test_runtime_reference_service.py`` (10) +
  ``tests/test_policy_contract_migration.py`` (3)
- ``pytest --collect-only``: 296 tests collected, 0 errors
- env constructs from smoke YAML; ``jax.jit(env.reset)(rng)`` returns a
  valid 35-field ``WildRobotInfo``; ``jax.jit(env.step)`` advances
  ``loc_ref_offline_step_idx`` 0 → N; vmap over 4 envs works
- placeholder reward = ``reward_weights.alive`` per step until termination

**Remaining for the v0.20.1 smoke:**
- **Task #49** — imitation-dominant reward family
  (``ref/q_ref_track``, ``ref/body_quat_track``,
  ``ref/feet_pos_track``, ``ref/contact_match``, secondary
  ``cmd/forward_velocity_track``, regularizers per
  ``walking_training.md`` v0.20.1 section); tune the smoke YAML's
  reward weights + PPO hyperparams.  Lands in a fresh session.

**Deferred past v0.20.1 smoke:**
- v0.20.2 hardware-deployable runtime adapter (no current code path
  uses ``RuntimeReferenceService`` from a hardware runner; ``§8`` lists
  ``runtime/wr_runtime/control/run_policy.py`` and
  ``replay_policy.py`` as "to update" when this lands)
- Multi-command training (Q3 stacked-arrays design)
- Per-env random start offsets (Q4)
- Asymmetric per-joint residual clip (Q5)

**Next-session execution plan (rewrite-shaped, replaces the original
6-commit surgical plan)**:

1. **Reuse audit** — read the existing 6533-line ``wildrobot_env.py``
   and identify what to extract verbatim into the new env:
   - model load, calibration ops, signals adapter, MJX physics step
   - action filter (lowpass v1) + residual action composition
   - domain randomization sampling
   - push schedule sampling
   - termination conditions (height + pitch/roll bounds)
   - obs builder dispatch (v5 layout)
   - core ``WildRobotEnvState`` shape

2. **Drop list** — explicit list of subsystems to NOT carry forward:
   - ``_fsm_compute_ctrl`` + ``fsm_*`` state (M3 era)
   - ``_mpc_standing_compute_ctrl`` + ``mpc_*`` state (v0.17.3 pivot)
   - teacher targets (``teacher_*`` state, helper modules)
   - recovery-metrics tracking (``recovery_*`` state)
   - the v0.19.5c reward family (``compute_*_reward`` helpers, m3_*
     tracking, dense_progress, slip nuance) — replaced by the
     imitation-dominant family in Task 3
   - ``_compute_nominal_q_ref_from_loc_ref`` (v1/v2 IK)
   - ``_apply_startup_support_rate_limiter`` (FSM-mode helper)
   - ``_step_walking_reference_jax`` (v1 helper)
   - all v1/v2 brake-scale / support-scale / support-health helpers

3. **New env structure** (target ~1500-2000 lines, single file):
   - ``WildRobotEnv.__init__``: model load + calib + signals adapter
     + Layer-2 service init (already designed in §1 / commit ``a3101cd``)
   - ``WildRobotEnv.reset``: keyframe init → seed step 0 of the offline
     trajectory → build initial ``WildRobotEnvState``
   - ``WildRobotEnv.step``: read window from service →
     ``q_target = q_ref + residual(policy_action)`` (absolute mode) →
     MJX physics step → obs / placeholder reward / termination
   - ``WildRobotInfo``: pruned to only the fields the rewrite uses
     (existing M3/MPC/recovery/teacher fields removed in step 4 below)

4. **WildRobotInfo cleanup** (separate commit after the rewrite):
   - keep: ``step_count``, ``prev_action``, ``pending_action``,
     ``truncated``, ``velocity_cmd``, ``prev_root_*``, ``imu_*_hist``,
     ``foot_contacts``, ``root_height``, ``prev_left/right_loaded``,
     ``cycle_start_forward_x``, ``last_touchdown_*``, ``critic_obs``,
     ``loc_ref_*`` (the obs-feeding ones), ``nominal_q_ref``,
     ``loc_ref_offline_step_idx``, ``loc_ref_offline_command_id``,
     ``push_schedule``, ``domain_rand_*``
   - drop: ``fsm_*`` (9 fields), ``mpc_*`` (5 fields), ``teacher_*``
     (7 fields), ``recovery_*`` (~25 fields), ``loc_ref_mode_*``,
     ``loc_ref_startup_route_*`` (FSM-era), ``loc_ref_com_x0_at_*``
     (v2-specific)

5. **Placeholder reward** for the rewrite commit:
   - ``r = alive`` only (1.0 per step until termination)
   - This lets the env JIT, reset, and step end-to-end so we can validate
     wiring before Task 3 designs the real imitation reward family.

6. **Validation** before declaring the rewrite done:
   - env constructs cleanly with the v0.20.1 smoke config (Task 3 YAML)
   - ``jax.jit(env.reset)(rng)`` returns a valid state
   - ``jax.jit(env.step)(state, zero_action)`` runs N steps without
     error and ``state.info[WR_INFO_KEY].loc_ref_offline_step_idx``
     advances 0 → N
   - the §7 wiring test (``tests/test_v0201_env_zero_action.py``)
     passes: ``target_q == q_ref_lib`` exactly when
     ``policy_action == 0``
   - parity tests (``tests/test_policy_contract_parity.py`` 7 cases)
     still pass

7. **Cleanup commits** after the rewrite:
   - delete deprecated runtime helpers (``loc_ref_runtime[_v2].py``,
     ``run_walking.py``) + update ``run_policy.py`` /
     ``replay_policy.py`` to drop ``RuntimeLocRefBuilder``
   - delete obsolete configs / tools / control/locomotion helpers
     (per §8 list)
   - clean dead config fields and dead ``WildRobotInfo`` fields per §4 above

8. **Hand-off** to Task 3 (imitation-dominant reward + smoke YAML +
   PPO runner).

**Estimated scope of the rewrite commit**: ~1500-2000 lines of new
``wildrobot_env.py``, with ~6533 lines deleted (the old file).
Net repo line change: roughly -4500.

**Pre-rewrite checklist for the next session**:

- Read ``training/eval/visualize_policy.py`` and ``train.py`` to confirm
  what env interface they call into (``env.reset``, ``env.step``,
  ``env.observation_size``, ``env.action_size``, ``env.dt``,
  ``env.mj_model``, ``env.mjx_model``)
- Read the v0.20.1 smoke YAML (Task 3 will write it before the rewrite
  begins) so the env is built to consume the right config fields
- Verify ``policy_contract.calib.JaxCalibOps`` can be reused as-is (it
  was designed to be env-agnostic)
- Identify which ``compute_*_reward`` helpers in the existing env file
  are pure functions worth keeping in a shared ``training/envs/rewards.py``
  vs which ones are v0.19.5c-specific dead code

## 11. What this note does NOT cover

- The new imitation reward family (Task 3 — separate design pass)
- The smoke YAML config (Task 3)
- The PPO runner / launch script (Task 3)
- Multi-command training (deferred — explicitly out of scope per the smoke)
- Stop / yaw / resume commands (deferred to v0.20.4)
- Hardware-deployable runtime adapter (deferred to v0.20.2)

---

**Reviewer ask:** confirm the §2 bypass list, the §4.1 residual-mode introduction,
the §5 obs-layout reuse decision, and the §7 zero-action sanity check before
code lands.  Open questions Q1-Q5 also benefit from explicit yes/no.

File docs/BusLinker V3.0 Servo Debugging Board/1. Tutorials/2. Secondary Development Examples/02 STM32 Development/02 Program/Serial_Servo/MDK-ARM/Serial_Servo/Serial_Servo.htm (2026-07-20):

# Static Call Graph for image Serial_Servo\Serial_Servo.axf

#<CALLGRAPH># ARM Linker, 6220000: Last Updated: Tue Oct 28 19:26:00 2025

### Maximum Stack Usage = 392 bytes + Unknown(Cycles, Untraceable Function Pointers)

### Call chain for Maximum Stack Depth:

main ⇒ SystemClock_Config ⇒ HAL_RCC_ClockConfig ⇒ HAL_InitTick ⇒ HAL_NVIC_SetPriority ⇒ NVIC_EncodePriority

### Mutually Recursive functions

- ADC1_2_IRQHandler ⇒ ADC1_2_IRQHandler

### Function Pointers

- ADC1_2_IRQHandler from startup_stm32f103xb.o(.text) referenced from startup_stm32f103xb.o(RESET)
- BusFault_Handler from stm32f1xx_it.o(.text.BusFault_Handler) referenced from startup_stm32f103xb.o(RESET)
- CAN1_RX1_IRQHandler from startup_stm32f103xb.o(.text) referenced from startup_stm32f103xb.o(RESET)
- CAN1_SCE_IRQHandler from startup_stm32f103xb.o(.text) referenced from startup_stm32f103xb.o(RESET)
- DMA1_Channel1_IRQHandler from startup_stm32f103xb.o(.text) referenced from startup_stm32f103xb.o(RESET)
- DMA1_Channel2_IRQHandler from startup_stm32f103xb.o(.text) referenced from startup_stm32f103xb.o(RESET)
- DMA1_Channel3_IRQHandler from startup_stm32f103xb.o(.text) referenced from startup_stm32f103xb.o(RESET)
- DMA1_Channel4_IRQHandler from startup_stm32f103xb.o(.text) referenced from startup_stm32f103xb.o(RESET)
- DMA1_Channel5_IRQHandler from startup_stm32f103xb.o(.text) referenced from startup_stm32f103xb.o(RESET)
- DMA1_Channel6_IRQHandler from stm32f1xx_it.o(.text.DMA1_Channel6_IRQHandler) referenced from startup_stm32f103xb.o(RESET)
- DMA1_Channel7_IRQHandler from startup_stm32f103xb.o(.text) referenced from startup_stm32f103xb.o(RESET)
- DebugMon_Handler from stm32f1xx_it.o(.text.DebugMon_Handler) referenced from startup_stm32f103xb.o(RESET)
- EXTI0_IRQHandler from startup_stm32f103xb.o(.text) referenced from startup_stm32f103xb.o(RESET)
- EXTI15_10_IRQHandler from startup_stm32f103xb.o(.text) referenced from startup_stm32f103xb.o(RESET)
- EXTI1_IRQHandler from startup_stm32f103xb.o(.text) referenced from startup_stm32f103xb.o(RESET)
- EXTI2_IRQHandler from startup_stm32f103xb.o(.text) referenced from startup_stm32f103xb.o(RESET)
- EXTI3_IRQHandler from startup_stm32f103xb.o(.text) referenced from startup_stm32f103xb.o(RESET)
- EXTI4_IRQHandler from startup_stm32f103xb.o(.text) referenced from startup_stm32f103xb.o(RESET)
- EXTI9_5_IRQHandler from startup_stm32f103xb.o(.text) referenced from startup_stm32f103xb.o(RESET)
- FLASH_IRQHandler from startup_stm32f103xb.o(.text) referenced from startup_stm32f103xb.o(RESET)
- HAL_UARTEx_RxEventCallback from stm32f1xx_hal_uart.o(.text.HAL_UARTEx_RxEventCallback) referenced 2 times from stm32f1xx_hal_uart.o(.text.UART_InitCallbacksToDefault)
- HAL_UART_AbortCpltCallback from stm32f1xx_hal_uart.o(.text.HAL_UART_AbortCpltCallback) referenced 2 times from stm32f1xx_hal_uart.o(.text.UART_InitCallbacksToDefault)
- HAL_UART_AbortReceiveCpltCallback from stm32f1xx_hal_uart.o(.text.HAL_UART_AbortReceiveCpltCallback) referenced 2 times from stm32f1xx_hal_uart.o(.text.UART_InitCallbacksToDefault)
- HAL_UART_AbortTransmitCpltCallback from stm32f1xx_hal_uart.o(.text.HAL_UART_AbortTransmitCpltCallback) referenced 2 times from stm32f1xx_hal_uart.o(.text.UART_InitCallbacksToDefault)
- HAL_UART_ErrorCallback from stm32f1xx_hal_uart.o(.text.HAL_UART_ErrorCallback) referenced 2 times from stm32f1xx_hal_uart.o(.text.UART_InitCallbacksToDefault)
- HAL_UART_MspInit from usart.o(.text.HAL_UART_MspInit) referenced 2 times from stm32f1xx_hal_uart.o(.text.HAL_UART_Init)
- HAL_UART_RxCpltCallback from stm32f1xx_hal_uart.o(.text.HAL_UART_RxCpltCallback) referenced 2 times from stm32f1xx_hal_uart.o(.text.UART_InitCallbacksToDefault)
- HAL_UART_RxHalfCpltCallback from stm32f1xx_hal_uart.o(.text.HAL_UART_RxHalfCpltCallback) referenced 2 times from stm32f1xx_hal_uart.o(.text.UART_InitCallbacksToDefault)
- HAL_UART_TxCpltCallback from stm32f1xx_hal_uart.o(.text.HAL_UART_TxCpltCallback) referenced 2 times from stm32f1xx_hal_uart.o(.text.UART_InitCallbacksToDefault)
- HAL_UART_TxHalfCpltCallback from stm32f1xx_hal_uart.o(.text.HAL_UART_TxHalfCpltCallback) referenced 2 times from stm32f1xx_hal_uart.o(.text.UART_InitCallbacksToDefault)
- HardFault_Handler from stm32f1xx_it.o(.text.HardFault_Handler) referenced from startup_stm32f103xb.o(RESET)
- I2C1_ER_IRQHandler from startup_stm32f103xb.o(.text) referenced from startup_stm32f103xb.o(RESET)
- I2C1_EV_IRQHandler from startup_stm32f103xb.o(.text) referenced from startup_stm32f103xb.o(RESET)
- I2C2_ER_IRQHandler from startup_stm32f103xb.o(.text) referenced from startup_stm32f103xb.o(RESET)
- I2C2_EV_IRQHandler from startup_stm32f103xb.o(.text) referenced from startup_stm32f103xb.o(RESET)
- MemManage_Handler from stm32f1xx_it.o(.text.MemManage_Handler) referenced from startup_stm32f103xb.o(RESET)
- NMI_Handler from stm32f1xx_it.o(.text.NMI_Handler) referenced from startup_stm32f103xb.o(RESET)
- PVD_IRQHandler from startup_stm32f103xb.o(.text) referenced from startup_stm32f103xb.o(RESET)
- PendSV_Handler from stm32f1xx_it.o(.text.PendSV_Handler) referenced from startup_stm32f103xb.o(RESET)
- RCC_IRQHandler from startup_stm32f103xb.o(.text) referenced from startup_stm32f103xb.o(RESET)
- RTC_Alarm_IRQHandler from startup_stm32f103xb.o(.text) referenced from startup_stm32f103xb.o(RESET)
- RTC_IRQHandler from startup_stm32f103xb.o(.text) referenced from startup_stm32f103xb.o(RESET)
- Reset_Handler from startup_stm32f103xb.o(.text) referenced from startup_stm32f103xb.o(RESET)
- SPI1_IRQHandler from startup_stm32f103xb.o(.text) referenced from startup_stm32f103xb.o(RESET)
- SPI2_IRQHandler from startup_stm32f103xb.o(.text) referenced from startup_stm32f103xb.o(RESET)
- SVC_Handler from stm32f1xx_it.o(.text.SVC_Handler) referenced from startup_stm32f103xb.o(RESET)
- SysTick_Handler from stm32f1xx_it.o(.text.SysTick_Handler) referenced from startup_stm32f103xb.o(RESET)
- SystemInit from system_stm32f1xx.o(.text.SystemInit) referenced from startup_stm32f103xb.o(.text)
- TAMPER_IRQHandler from startup_stm32f103xb.o(.text) referenced from startup_stm32f103xb.o(RESET)
- TIM1_BRK_IRQHandler from startup_stm32f103xb.o(.text) referenced from startup_stm32f103xb.o(RESET)
- TIM1_CC_IRQHandler from startup_stm32f103xb.o(.text) referenced from startup_stm32f103xb.o(RESET)
- TIM1_TRG_COM_IRQHandler from startup_stm32f103xb.o(.text) referenced from startup_stm32f103xb.o(RESET)
- TIM1_UP_IRQHandler from startup_stm32f103xb.o(.text) referenced from startup_stm32f103xb.o(RESET)
- TIM2_IRQHandler from startup_stm32f103xb.o(.text) referenced from startup_stm32f103xb.o(RESET)
- TIM3_IRQHandler from startup_stm32f103xb.o(.text) referenced from startup_stm32f103xb.o(RESET)
- TIM4_IRQHandler from startup_stm32f103xb.o(.text) referenced from startup_stm32f103xb.o(RESET)
- UART_DMAAbortOnError from stm32f1xx_hal_uart.o(.text.UART_DMAAbortOnError) referenced 2 times from stm32f1xx_hal_uart.o(.text.HAL_UART_IRQHandler)
- UART_DMAError from stm32f1xx_hal_uart.o(.text.UART_DMAError) referenced 2 times from stm32f1xx_hal_uart.o(.text.UART_Start_Receive_DMA)
- UART_DMAReceiveCplt from stm32f1xx_hal_uart.o(.text.UART_DMAReceiveCplt) referenced 2 times from stm32f1xx_hal_uart.o(.text.UART_Start_Receive_DMA)
- UART_DMARxHalfCplt from stm32f1xx_hal_uart.o(.text.UART_DMARxHalfCplt) referenced 2 times from stm32f1xx_hal_uart.o(.text.UART_Start_Receive_DMA)
- USART1_IRQHandler from stm32f1xx_it.o(.text.USART1_IRQHandler) referenced from startup_stm32f103xb.o(RESET)
- USART2_IRQHandler from stm32f1xx_it.o(.text.USART2_IRQHandler) referenced from startup_stm32f103xb.o(RESET)
- USART3_IRQHandler from startup_stm32f103xb.o(.text) referenced from startup_stm32f103xb.o(RESET)
- USBWakeUp_IRQHandler from startup_stm32f103xb.o(.text) referenced from startup_stm32f103xb.o(RESET)
- USB_HP_CAN1_TX_IRQHandler from startup_stm32f103xb.o(.text) referenced from startup_stm32f103xb.o(RESET)
- USB_LP_CAN1_RX0_IRQHandler from startup_stm32f103xb.o(.text) referenced from startup_stm32f103xb.o(RESET)
- UsageFault_Handler from stm32f1xx_it.o(.text.UsageFault_Handler) referenced from startup_stm32f103xb.o(RESET)
- WWDG_IRQHandler from startup_stm32f103xb.o(.text) referenced from startup_stm32f103xb.o(RESET)
- __main from entry.o(.ARM.Collect$$$$00000000) referenced from startup_stm32f103xb.o(.text)
- _sputc from printfa.o(i._sputc) referenced from printfa.o(i.__0sprintf)
- main from main.o(.text.main) referenced from entry9a.o(.ARM.Collect$$$$0000000B)
- receive_dma_data from packet_handler.o(.text.receive_dma_data) referenced 2 times from packet_handler.o(.text.packt_init)
- servo_dma_receive_event_callback from hx_30hm.o(.text.servo_dma_receive_event_callback) referenced 2 times from hx_30hm.o(.text.servo_init)
- servo_uart_rx_error_callblack from hx_30hm.o(.text.servo_uart_rx_error_callblack) referenced 2 times from hx_30hm.o(.text.servo_init)
- tramsmit_data from packet_handler.o(.text.tramsmit_data) referenced 2 times from packet_handler.o(.text.packt_init)

### Global Symbols

__main (Thumb, 0 bytes, Stack size unknown bytes, entry.o(.ARM.Collect$$$$00000000))
[Address Reference Count : 1]

- startup_stm32f103xb.o(.text)

_main_stk (Thumb, 0 bytes, Stack size unknown bytes, entry2.o(.ARM.Collect$$$$00000001))

_main_scatterload (Thumb, 0 bytes, Stack size unknown bytes, entry5.o(.ARM.Collect$$$$00000004))

[Calls]

- >> __scatterload

__main_after_scatterload (Thumb, 0 bytes, Stack size unknown bytes, entry5.o(.ARM.Collect$$$$00000004))

[Called By]

- >> __scatterload

_main_clock (Thumb, 0 bytes, Stack size unknown bytes, entry7b.o(.ARM.Collect$$$$00000008))

_main_cpp_init (Thumb, 0 bytes, Stack size unknown bytes, entry8b.o(.ARM.Collect$$$$0000000A))

_main_init (Thumb, 0 bytes, Stack size unknown bytes, entry9a.o(.ARM.Collect$$$$0000000B))

__rt_final_cpp (Thumb, 0 bytes, Stack size unknown bytes, entry10a.o(.ARM.Collect$$$$0000000D))

__rt_final_exit (Thumb, 0 bytes, Stack size unknown bytes, entry11a.o(.ARM.Collect$$$$0000000F))

Reset_Handler (Thumb, 8 bytes, Stack size 0 bytes, startup_stm32f103xb.o(.text))
[Address Reference Count : 1]

- startup_stm32f103xb.o(RESET)

ADC1_2_IRQHandler (Thumb, 0 bytes, Stack size 0 bytes, startup_stm32f103xb.o(.text))

[Calls]

- >> ADC1_2_IRQHandler

[Called By]

- >> ADC1_2_IRQHandler

[Address Reference Count : 1]

- startup_stm32f103xb.o(RESET)

CAN1_RX1_IRQHandler (Thumb, 0 bytes, Stack size 0 bytes, startup_stm32f103xb.o(.text))
[Address Reference Count : 1]

- startup_stm32f103xb.o(RESET)

CAN1_SCE_IRQHandler (Thumb, 0 bytes, Stack size 0 bytes, startup_stm32f103xb.o(.text))
[Address Reference Count : 1]

- startup_stm32f103xb.o(RESET)

DMA1_Channel1_IRQHandler (Thumb, 0 bytes, Stack size 0 bytes, startup_stm32f103xb.o(.text))
[Address Reference Count : 1]

- startup_stm32f103xb.o(RESET)

DMA1_Channel2_IRQHandler (Thumb, 0 bytes, Stack size 0 bytes, startup_stm32f103xb.o(.text))
[Address Reference Count : 1]

- startup_stm32f103xb.o(RESET)

DMA1_Channel3_IRQHandler (Thumb, 0 bytes, Stack size 0 bytes, startup_stm32f103xb.o(.text))
[Address Reference Count : 1]

- startup_stm32f103xb.o(RESET)

DMA1_Channel4_IRQHandler (Thumb, 0 bytes, Stack size 0 bytes, startup_stm32f103xb.o(.text))
[Address Reference Count : 1]

- startup_stm32f103xb.o(RESET)

DMA1_Channel5_IRQHandler (Thumb, 0 bytes, Stack size 0 bytes, startup_stm32f103xb.o(.text))
[Address Reference Count : 1]

- startup_stm32f103xb.o(RESET)

DMA1_Channel7_IRQHandler (Thumb, 0 bytes, Stack size 0 bytes, startup_stm32f103xb.o(.text))
[Address Reference Count : 1]

- startup_stm32f103xb.o(RESET)

EXTI0_IRQHandler (Thumb, 0 bytes, Stack size 0 bytes, startup_stm32f103xb.o(.text))
[Address Reference Count : 1]

- startup_stm32f103xb.o(RESET)

EXTI15_10_IRQHandler (Thumb, 0 bytes, Stack size 0 bytes, startup_stm32f103xb.o(.text))
[Address Reference Count : 1]

- startup_stm32f103xb.o(RESET)

EXTI1_IRQHandler (Thumb, 0 bytes, Stack size 0 bytes, startup_stm32f103xb.o(.text))
[Address Reference Count : 1]

- startup_stm32f103xb.o(RESET)

EXTI2_IRQHandler (Thumb, 0 bytes, Stack size 0 bytes, startup_stm32f103xb.o(.text))
[Address Reference Count : 1]

- startup_stm32f103xb.o(RESET)

EXTI3_IRQHandler (Thumb, 0 bytes, Stack size 0 bytes, startup_stm32f103xb.o(.text))
[Address Reference Count : 1]

- startup_stm32f103xb.o(RESET)

EXTI4_IRQHandler (Thumb, 0 bytes, Stack size 0 bytes, startup_stm32f103xb.o(.text))
[Address Reference Count : 1]

- startup_stm32f103xb.o(RESET)

EXTI9_5_IRQHandler (Thumb, 0 bytes, Stack size 0 bytes, startup_stm32f103xb.o(.text))
[Address Reference Count : 1]

- startup_stm32f103xb.o(RESET)

FLASH_IRQHandler (Thumb, 0 bytes, Stack size 0 bytes, startup_stm32f103xb.o(.text))
[Address Reference Count : 1]

- startup_stm32f103xb.o(RESET)

I2C1_ER_IRQHandler (Thumb, 0 bytes, Stack size 0 bytes, startup_stm32f103xb.o(.text))
[Address Reference Count : 1]

- startup_stm32f103xb.o(RESET)

I2C1_EV_IRQHandler (Thumb, 0 bytes, Stack size 0 bytes, startup_stm32f103xb.o(.text))
[Address Reference Count : 1]

- startup_stm32f103xb.o(RESET)

I2C2_ER_IRQHandler (Thumb, 0 bytes, Stack size 0 bytes, startup_stm32f103xb.o(.text))
[Address Reference Count : 1]

- startup_stm32f103xb.o(RESET)

I2C2_EV_IRQHandler (Thumb, 0 bytes, Stack size 0 bytes, startup_stm32f103xb.o(.text))
[Address Reference Count : 1]

- startup_stm32f103xb.o(RESET)

PVD_IRQHandler (Thumb, 0 bytes, Stack size 0 bytes, startup_stm32f103xb.o(.text))
[Address Reference Count : 1]

- startup_stm32f103xb.o(RESET)

RCC_IRQHandler (Thumb, 0 bytes, Stack size 0 bytes, startup_stm32f103xb.o(.text))
[Address Reference Count : 1]

- startup_stm32f103xb.o(RESET)

RTC_Alarm_IRQHandler (Thumb, 0 bytes, Stack size 0 bytes, startup_stm32f103xb.o(.text))
[Address Reference Count : 1]

- startup_stm32f103xb.o(RESET)

RTC_IRQHandler (Thumb, 0 bytes, Stack size 0 bytes, startup_stm32f103xb.o(.text))
[Address Reference Count : 1]

- startup_stm32f103xb.o(RESET)

SPI1_IRQHandler (Thumb, 0 bytes, Stack size 0 bytes, startup_stm32f103xb.o(.text))
[Address Reference Count : 1]

- startup_stm32f103xb.o(RESET)

SPI2_IRQHandler (Thumb, 0 bytes, Stack size 0 bytes, startup_stm32f103xb.o(.text))
[Address Reference Count : 1]

- startup_stm32f103xb.o(RESET)

TAMPER_IRQHandler (Thumb, 0 bytes, Stack size 0 bytes, startup_stm32f103xb.o(.text))
[Address Reference Count : 1]

- startup_stm32f103xb.o(RESET)

TIM1_BRK_IRQHandler (Thumb, 0 bytes, Stack size 0 bytes, startup_stm32f103xb.o(.text))
[Address Reference Count : 1]

- startup_stm32f103xb.o(RESET)

TIM1_CC_IRQHandler (Thumb, 0 bytes, Stack size 0 bytes, startup_stm32f103xb.o(.text))
[Address Reference Count : 1]

- startup_stm32f103xb.o(RESET)

TIM1_TRG_COM_IRQHandler (Thumb, 0 bytes, Stack size 0 bytes, startup_stm32f103xb.o(.text))
[Address Reference Count : 1]

- startup_stm32f103xb.o(RESET)

TIM1_UP_IRQHandler (Thumb, 0 bytes, Stack size 0 bytes, startup_stm32f103xb.o(.text))
[Address Reference Count : 1]

- startup_stm32f103xb.o(RESET)

TIM2_IRQHandler (Thumb, 0 bytes, Stack size 0 bytes, startup_stm32f103xb.o(.text))
[Address Reference Count : 1]

- startup_stm32f103xb.o(RESET)

TIM3_IRQHandler (Thumb, 0 bytes, Stack size 0 bytes, startup_stm32f103xb.o(.text))
[Address Reference Count : 1]

- startup_stm32f103xb.o(RESET)

TIM4_IRQHandler (Thumb, 0 bytes, Stack size 0 bytes, startup_stm32f103xb.o(.text))
[Address Reference Count : 1]

- startup_stm32f103xb.o(RESET)

USART3_IRQHandler (Thumb, 0 bytes, Stack size 0 bytes, startup_stm32f103xb.o(.text))
[Address Reference Count : 1]

- startup_stm32f103xb.o(RESET)

USBWakeUp_IRQHandler (Thumb, 0 bytes, Stack size 0 bytes, startup_stm32f103xb.o(.text))
[Address Reference Count : 1]

- startup_stm32f103xb.o(RESET)

USB_HP_CAN1_TX_IRQHandler (Thumb, 0 bytes, Stack size 0 bytes, startup_stm32f103xb.o(.text))
[Address Reference Count : 1]

- startup_stm32f103xb.o(RESET)

USB_LP_CAN1_RX0_IRQHandler (Thumb, 0 bytes, Stack size 0 bytes, startup_stm32f103xb.o(.text))
[Address Reference Count : 1]

- startup_stm32f103xb.o(RESET)

WWDG_IRQHandler (Thumb, 0 bytes, Stack size 0 bytes, startup_stm32f103xb.o(.text))
[Address Reference Count : 1]

- startup_stm32f103xb.o(RESET)

__aeabi_memcpy (Thumb, 36 bytes, Stack size 0 bytes, memcpya.o(.text))

[Called By]

- >> lwrb_read_ex
- >> lwrb_write_ex

__aeabi_memcpy4 (Thumb, 0 bytes, Stack size 0 bytes, memcpya.o(.text), UNUSED)

__aeabi_memcpy8 (Thumb, 0 bytes, Stack size 0 bytes, memcpya.o(.text), UNUSED)

__aeabi_memset (Thumb, 14 bytes, Stack size 0 bytes, memseta.o(.text), UNUSED)

[Called By]

- >> _memset$wrapper
- >> __aeabi_memclr

__aeabi_memset4 (Thumb, 0 bytes, Stack size 0 bytes, memseta.o(.text), UNUSED)

__aeabi_memset8 (Thumb, 0 bytes, Stack size 0 bytes, memseta.o(.text), UNUSED)

__aeabi_memclr (Thumb, 4 bytes, Stack size 0 bytes, memseta.o(.text), UNUSED)

[Calls]

- >> __aeabi_memset

__aeabi_memclr4 (Thumb, 0 bytes, Stack size 0 bytes, memseta.o(.text))

[Called By]

- >> packt_init
- >> SystemClock_Config

__aeabi_memclr8 (Thumb, 0 bytes, Stack size 0 bytes, memseta.o(.text), UNUSED)

_memset$wrapper (Thumb, 18 bytes, Stack size 8 bytes, memseta.o(.text), UNUSED)

[Calls]

- >> __aeabi_memset

__aeabi_uidiv (Thumb, 0 bytes, Stack size 12 bytes, uidiv.o(.text), UNUSED)

__aeabi_uidivmod (Thumb, 44 bytes, Stack size 12 bytes, uidiv.o(.text), UNUSED)

[Called By]

- >> _printf_core

__aeabi_uldivmod (Thumb, 98 bytes, Stack size 40 bytes, uldiv.o(.text), UNUSED)

[Calls]

- >> __aeabi_llsr
- >> __aeabi_llsl

[Called By]

- >> _printf_core
- >> _fp_digits

__I$use$fp (Thumb, 0 bytes, Stack size 48 bytes, iusefp.o(.text), UNUSED)

__aeabi_dadd (Thumb, 322 bytes, Stack size 48 bytes, dadd.o(.text), UNUSED)

[Calls]

- >> __aeabi_lasr
- >> __aeabi_llsl
- >> _double_round
- >> _double_epilogue

[Called By]

- >> _fp_digits
- >> __aeabi_drsub
- >> __aeabi_dsub

__aeabi_dsub (Thumb, 6 bytes, Stack size 0 bytes, dadd.o(.text), UNUSED)

[Calls]

- >> __aeabi_dadd

__aeabi_drsub (Thumb, 6 bytes, Stack size 0 bytes, dadd.o(.text), UNUSED)

[Calls]

- >> __aeabi_dadd

__aeabi_dmul (Thumb, 228 bytes, Stack size 48 bytes, dmul.o(.text), UNUSED)

[Calls]

- >> _double_epilogue

[Called By]

- >> _fp_digits

__aeabi_ddiv (Thumb, 222 bytes, Stack size 32 bytes, ddiv.o(.text), UNUSED)

[Calls]

- >> _double_round

[Called By]

- >> _fp_digits

__aeabi_d2ulz (Thumb, 48 bytes, Stack size 0 bytes, dfixul.o(.text), UNUSED)

[Calls]

- >> __aeabi_llsr
- >> __aeabi_llsl

[Called By]

- >> _fp_digits

__aeabi_cdrcmple (Thumb, 48 bytes, Stack size 0 bytes, cdrcmple.o(.text), UNUSED)

[Called By]

- >> _fp_digits

__scatterload (Thumb, 38 bytes, Stack size 0 bytes, init.o(.text))

[Calls]

- >> __main_after_scatterload

[Called By]

- >> _main_scatterload

__scatterload_rt2 (Thumb, 0 bytes, Stack size 0 bytes, init.o(.text), UNUSED)

__aeabi_llsl (Thumb, 30 bytes, Stack size 0 bytes, llshl.o(.text), UNUSED)

[Called By]

- >> _double_epilogue
- >> __aeabi_uldivmod
- >> __aeabi_dadd
- >> __aeabi_d2ulz

_ll_shift_l (Thumb, 0 bytes, Stack size 0 bytes, llshl.o(.text), UNUSED)

__aeabi_llsr (Thumb, 32 bytes, Stack size 0 bytes, llushr.o(.text), UNUSED)

[Called By]

- >> _double_epilogue
- >> __aeabi_uldivmod
- >> __aeabi_d2ulz

_ll_ushift_r (Thumb, 0 bytes, Stack size 0 bytes, llushr.o(.text), UNUSED)

__aeabi_lasr (Thumb, 36 bytes, Stack size 0 bytes, llsshr.o(.text), UNUSED)

[Called By]

- >> __aeabi_dadd

_ll_sshift_r (Thumb, 0 bytes, Stack size 0 bytes, llsshr.o(.text), UNUSED)

_double_round (Thumb, 30 bytes, Stack size 8 bytes, depilogue.o(.text), UNUSED)

[Called By]

- >> _double_epilogue
- >> __aeabi_ddiv
- >> __aeabi_dadd

_double_epilogue (Thumb, 156 bytes, Stack size 32 bytes, depilogue.o(.text), UNUSED)

[Calls]

- >> __aeabi_llsr
- >> __aeabi_llsl
- >> _double_round

[Called By]

- >> __aeabi_dmul
- >> __aeabi_dadd

BusFault_Handler (Thumb, 4 bytes, Stack size 0 bytes, stm32f1xx_it.o(.text.BusFault_Handler))
[Address Reference Count : 1]

- startup_stm32f103xb.o(RESET)

DMA1_Channel6_IRQHandler (Thumb, 16 bytes, Stack size 8 bytes, stm32f1xx_it.o(.text.DMA1_Channel6_IRQHandler))

[Stack]

- Max Depth = 72
- Call Chain = DMA1_Channel6_IRQHandler ⇒ HAL_DMA_IRQHandler

[Calls]

- >> HAL_DMA_IRQHandler

[Address Reference Count : 1]

- startup_stm32f103xb.o(RESET)

DebugMon_Handler (Thumb, 2 bytes, Stack size 0 bytes, stm32f1xx_it.o(.text.DebugMon_Handler))
[Address Reference Count : 1]

- startup_stm32f103xb.o(RESET)

Error_Handler (Thumb, 6 bytes, Stack size 0 bytes, main.o(.text.Error_Handler))

[Called By]

- >> HAL_UART_MspInit
- >> MX_USART2_UART_Init
- >> MX_USART1_UART_Init
- >> SystemClock_Config

HAL_DMA_Abort (Thumb, 124 bytes, Stack size 12 bytes, stm32f1xx_hal_dma.o(.text.HAL_DMA_Abort))

[Stack]

- Max Depth = 12
- Call Chain = HAL_DMA_Abort

[Called By]

- >> HAL_UART_IRQHandler

HAL_DMA_Abort_IT (Thumb, 284 bytes, Stack size 40 bytes, stm32f1xx_hal_dma.o(.text.HAL_DMA_Abort_IT))

[Stack]

- Max Depth = 40
- Call Chain = HAL_DMA_Abort_IT

[Called By]

- >> HAL_UART_IRQHandler

HAL_DMA_IRQHandler (Thumb, 646 bytes, Stack size 64 bytes, stm32f1xx_hal_dma.o(.text.HAL_DMA_IRQHandler))

[Stack]

- Max Depth = 64
- Call Chain = HAL_DMA_IRQHandler

[Called By]

- >> DMA1_Channel6_IRQHandler

HAL_DMA_Init (Thumb, 174 bytes, Stack size 12 bytes, stm32f1xx_hal_dma.o(.text.HAL_DMA_Init))

[Stack]

- Max Depth = 12
- Call Chain = HAL_DMA_Init

[Called By]

- >> HAL_UART_MspInit

HAL_DMA_Start_IT (Thumb, 202 bytes, Stack size 32 bytes, stm32f1xx_hal_dma.o(.text.HAL_DMA_Start_IT))

[Stack]

- Max Depth = 48
- Call Chain = HAL_DMA_Start_IT ⇒ DMA_SetConfig

[Calls]

- >> DMA_SetConfig

[Called By]

- >> UART_Start_Receive_DMA

HAL_GPIO_Init (Thumb, 798 bytes, Stack size 64 bytes, stm32f1xx_hal_gpio.o(.text.HAL_GPIO_Init))

[Stack]

- Max Depth = 64
- Call Chain = HAL_GPIO_Init

[Called By]

- >> HAL_UART_MspInit
- >> MX_GPIO_Init

HAL_GPIO_WritePin (Thumb, 46 bytes, Stack size 8 bytes, stm32f1xx_hal_gpio.o(.text.HAL_GPIO_WritePin))

[Stack]

- Max Depth = 8
- Call Chain = HAL_GPIO_WritePin

[Called By]

- >> MX_GPIO_Init

HAL_GetTick (Thumb, 12 bytes, Stack size 0 bytes, stm32f1xx_hal.o(.text.HAL_GetTick))

[Called By]

- >> UART_WaitOnFlagUntilTimeout
- >> HAL_UART_Transmit
- >> HAL_RCC_ClockConfig
- >> HAL_RCC_OscConfig

HAL_IncTick (Thumb, 26 bytes, Stack size 0 bytes, stm32f1xx_hal.o(.text.HAL_IncTick))

[Called By]

- >> SysTick_Handler

HAL_Init (Thumb, 38 bytes, Stack size 8 bytes, stm32f1xx_hal.o(.text.HAL_Init))

[Stack]

- Max Depth = 88
- Call Chain = HAL_Init ⇒ HAL_InitTick ⇒ HAL_NVIC_SetPriority ⇒ NVIC_EncodePriority

[Calls]

- >> HAL_InitTick
- >> HAL_NVIC_SetPriorityGrouping
- >> HAL_MspInit

[Called By]

- >> main

HAL_InitTick (Thumb, 112 bytes, Stack size 16 bytes, stm32f1xx_hal.o(.text.HAL_InitTick))

[Stack]

- Max Depth = 80
- Call Chain = HAL_InitTick ⇒ HAL_NVIC_SetPriority ⇒ NVIC_EncodePriority

[Calls]

- >> HAL_SYSTICK_Config
- >> HAL_NVIC_SetPriority

[Called By]

- >> HAL_RCC_ClockConfig
- >> HAL_Init

HAL_MspInit (Thumb, 100 bytes, Stack size 12 bytes, stm32f1xx_hal_msp.o(.text.HAL_MspInit))

[Stack]

- Max Depth = 12
- Call Chain = HAL_MspInit

[Called By]

- >> HAL_Init

HAL_NVIC_EnableIRQ (Thumb, 20 bytes, Stack size 16 bytes, stm32f1xx_hal_cortex.o(.text.HAL_NVIC_EnableIRQ))

[Stack]

- Max Depth = 20
- Call Chain = HAL_NVIC_EnableIRQ ⇒ __NVIC_EnableIRQ

[Calls]

- >> __NVIC_EnableIRQ

[Called By]

- >> HAL_UART_MspInit
- >> MX_DMA_Init
- >> MX_NVIC_Init

HAL_NVIC_SetPriority (Thumb, 50 bytes, Stack size 32 bytes, stm32f1xx_hal_cortex.o(.text.HAL_NVIC_SetPriority))

[Stack]

- Max Depth = 64
- Call Chain = HAL_NVIC_SetPriority ⇒ NVIC_EncodePriority

[Calls]

- >> __NVIC_SetPriority
- >> NVIC_EncodePriority
- >> __NVIC_GetPriorityGrouping

[Called By]

- >> HAL_InitTick
- >> HAL_UART_MspInit
- >> MX_DMA_Init
- >> MX_NVIC_Init

HAL_NVIC_SetPriorityGrouping (Thumb, 16 bytes, Stack size 16 bytes, stm32f1xx_hal_cortex.o(.text.HAL_NVIC_SetPriorityGrouping))

[Stack]

- Max Depth = 28
- Call Chain = HAL_NVIC_SetPriorityGrouping ⇒ __NVIC_SetPriorityGrouping

[Calls]

- >> __NVIC_SetPriorityGrouping

[Called By]

- >> HAL_Init

HAL_RCC_ClockConfig (Thumb, 598 bytes, Stack size 24 bytes, stm32f1xx_hal_rcc.o(.text.HAL_RCC_ClockConfig))

[Stack]

- Max Depth = 104
- Call Chain = HAL_RCC_ClockConfig ⇒ HAL_InitTick ⇒ HAL_NVIC_SetPriority ⇒ NVIC_EncodePriority

[Calls]

- >> HAL_RCC_GetSysClockFreq
- >> HAL_InitTick
- >> HAL_GetTick

[Called By]

- >> SystemClock_Config

HAL_RCC_GetHCLKFreq (Thumb, 12 bytes, Stack size 0 bytes, stm32f1xx_hal_rcc.o(.text.HAL_RCC_GetHCLKFreq))

[Called By]

- >> HAL_RCC_GetPCLK1Freq
- >> HAL_RCC_GetPCLK2Freq

HAL_RCC_GetPCLK1Freq (Thumb, 34 bytes, Stack size 8 bytes, stm32f1xx_hal_rcc.o(.text.HAL_RCC_GetPCLK1Freq))

[Stack]

- Max Depth = 8
- Call Chain = HAL_RCC_GetPCLK1Freq

[Calls]

- >> HAL_RCC_GetHCLKFreq

[Called By]

- >> UART_SetConfig

HAL_RCC_GetPCLK2Freq (Thumb, 34 bytes, Stack size 8 bytes, stm32f1xx_hal_rcc.o(.text.HAL_RCC_GetPCLK2Freq))

[Stack]

- Max Depth = 8
- Call Chain = HAL_RCC_GetPCLK2Freq

[Calls]

- >> HAL_RCC_GetHCLKFreq

[Called By]

- >> UART_SetConfig

HAL_RCC_GetSysClockFreq (Thumb, 188 bytes, Stack size 24 bytes, stm32f1xx_hal_rcc.o(.text.HAL_RCC_GetSysClockFreq))

[Stack]

- Max Depth = 24
- Call Chain = HAL_RCC_GetSysClockFreq

[Called By]

- >> HAL_RCC_ClockConfig

HAL_RCC_OscConfig (Thumb, 1658 bytes, Stack size 32 bytes, stm32f1xx_hal_rcc.o(.text.HAL_RCC_OscConfig))

[Stack]

- Max Depth = 40
- Call Chain = HAL_RCC_OscConfig ⇒ RCC_Delay

[Calls]

- >> RCC_Delay
- >> HAL_GetTick

[Called By]

- >> SystemClock_Config

HAL_SYSTICK_Config (Thumb, 16 bytes, Stack size 16 bytes, stm32f1xx_hal_cortex.o(.text.HAL_SYSTICK_Config))

[Stack]

- Max Depth = 40
- Call Chain = HAL_SYSTICK_Config ⇒ SysTick_Config ⇒ __NVIC_SetPriority

[Calls]

- >> SysTick_Config

[Called By]

- >> HAL_InitTick

HAL_UARTEx_GetRxEventType (Thumb, 12 bytes, Stack size 4 bytes, stm32f1xx_hal_uart.o(.text.HAL_UARTEx_GetRxEventType))

[Stack]

- Max Depth = 4
- Call Chain = HAL_UARTEx_GetRxEventType

[Called By]

- >> servo_dma_receive_event_callback

HAL_UARTEx_ReceiveToIdle_DMA (Thumb, 184 bytes, Stack size 32 bytes, stm32f1xx_hal_uart.o(.text.HAL_UARTEx_ReceiveToIdle_DMA))

[Stack]

- Max Depth = 120
- Call Chain = HAL_UARTEx_ReceiveToIdle_DMA ⇒ UART_Start_Receive_DMA ⇒ HAL_DMA_Start_IT ⇒ DMA_SetConfig

[Calls]

- >> UART_Start_Receive_DMA

[Called By]

- >> receive_dma_data

HAL_UARTEx_RxEventCallback (Thumb, 12 bytes, Stack size 8 bytes, stm32f1xx_hal_uart.o(.text.HAL_UARTEx_RxEventCallback))

[Stack]

- Max Depth = 8
- Call Chain = HAL_UARTEx_RxEventCallback

[Address Reference Count : 1]

- stm32f1xx_hal_uart.o(.text.UART_InitCallbacksToDefault)

HAL_UART_AbortCpltCallback (Thumb, 8 bytes, Stack size 4 bytes, stm32f1xx_hal_uart.o(.text.HAL_UART_AbortCpltCallback))

[Stack]

- Max Depth = 4
- Call Chain = HAL_UART_AbortCpltCallback

[Address Reference Count : 1]

- stm32f1xx_hal_uart.o(.text.UART_InitCallbacksToDefault)

HAL_UART_AbortReceiveCpltCallback (Thumb, 8 bytes, Stack size 4 bytes, stm32f1xx_hal_uart.o(.text.HAL_UART_AbortReceiveCpltCallback))

[Stack]

- Max Depth = 4
- Call Chain = HAL_UART_AbortReceiveCpltCallback

[Address Reference Count : 1]

- stm32f1xx_hal_uart.o(.text.UART_InitCallbacksToDefault)

HAL_UART_AbortTransmitCpltCallback (Thumb, 8 bytes, Stack size 4 bytes, stm32f1xx_hal_uart.o(.text.HAL_UART_AbortTransmitCpltCallback))

[Stack]

- Max Depth = 4
- Call Chain = HAL_UART_AbortTransmitCpltCallback

[Address Reference Count : 1]

- stm32f1xx_hal_uart.o(.text.UART_InitCallbacksToDefault)

HAL_UART_ErrorCallback (Thumb, 8 bytes, Stack size 4 bytes, stm32f1xx_hal_uart.o(.text.HAL_UART_ErrorCallback))

[Stack]

- Max Depth = 4
- Call Chain = HAL_UART_ErrorCallback

[Address Reference Count : 1]

- stm32f1xx_hal_uart.o(.text.UART_InitCallbacksToDefault)

HAL_UART_IRQHandler (Thumb, 1066 bytes, Stack size 80 bytes, stm32f1xx_hal_uart.o(.text.HAL_UART_IRQHandler))

[Stack]

- Max Depth = 120
- Call Chain = HAL_UART_IRQHandler ⇒ HAL_DMA_Abort_IT

[Calls]

- >> HAL_DMA_Abort_IT
- >> HAL_DMA_Abort
- >> UART_EndTransmit_IT
- >> UART_Transmit_IT
- >> UART_Receive_IT
- >> UART_EndRxTransfer

[Called By]

- >> USART2_IRQHandler
- >> USART1_IRQHandler

HAL_UART_Init (Thumb, 186 bytes, Stack size 16 bytes, stm32f1xx_hal_uart.o(.text.HAL_UART_Init))

[Stack]

- Max Depth = 48
- Call Chain = HAL_UART_Init ⇒ UART_SetConfig ⇒ HAL_RCC_GetPCLK1Freq

[Calls]

- >> UART_InitCallbacksToDefault
- >> UART_SetConfig

[Called By]

- >> MX_USART2_UART_Init
- >> MX_USART1_UART_Init

HAL_UART_MspInit (Thumb, 378 bytes, Stack size 72 bytes, usart.o(.text.HAL_UART_MspInit))

[Stack]

- Max Depth = 136
- Call Chain = HAL_UART_MspInit ⇒ HAL_GPIO_Init

[Calls]

- >> HAL_DMA_Init
- >> HAL_GPIO_Init
- >> HAL_NVIC_EnableIRQ
- >> HAL_NVIC_SetPriority
- >> Error_Handler

[Address Reference Count : 1]

- stm32f1xx_hal_uart.o(.text.HAL_UART_Init)

HAL_UART_RegisterCallback (Thumb, 290 bytes, Stack size 28 bytes, stm32f1xx_hal_uart.o(.text.HAL_UART_RegisterCallback))

[Stack]

- Max Depth = 28
- Call Chain = HAL_UART_RegisterCallback

[Called By]

- >> servo_init

HAL_UART_RegisterRxEventCallback (Thumb, 138 bytes, Stack size 16 bytes, stm32f1xx_hal_uart.o(.text.HAL_UART_RegisterRxEventCallback))

[Stack]

- Max Depth = 16
- Call Chain = HAL_UART_RegisterRxEventCallback

[Called By]

- >> servo_init

HAL_UART_RxCpltCallback (Thumb, 8 bytes, Stack size 4 bytes, stm32f1xx_hal_uart.o(.text.HAL_UART_RxCpltCallback))

[Stack]

- Max Depth = 4
- Call Chain = HAL_UART_RxCpltCallback

[Address Reference Count : 1]

- stm32f1xx_hal_uart.o(.text.UART_InitCallbacksToDefault)

HAL_UART_RxHalfCpltCallback (Thumb, 8 bytes, Stack size 4 bytes, stm32f1xx_hal_uart.o(.text.HAL_UART_RxHalfCpltCallback))

[Stack]

- Max Depth = 4
- Call Chain = HAL_UART_RxHalfCpltCallback

[Address Reference Count : 1]

- stm32f1xx_hal_uart.o(.text.UART_InitCallbacksToDefault)

HAL_UART_Transmit (Thumb, 304 bytes, Stack size 48 bytes, stm32f1xx_hal_uart.o(.text.HAL_UART_Transmit))

[Stack]

- Max Depth = 96
- Call Chain = HAL_UART_Transmit ⇒ UART_WaitOnFlagUntilTimeout ⇒ UART_EndRxTransfer

[Calls]

- >> HAL_GetTick
- >> UART_WaitOnFlagUntilTimeout

[Called By]

- >> tramsmit_data
- >> serial_printf_string

HAL_UART_TxCpltCallback (Thumb, 8 bytes, Stack size 4 bytes, stm32f1xx_hal_uart.o(.text.HAL_UART_TxCpltCallback))

[Stack]

- Max Depth = 4
- Call Chain = HAL_UART_TxCpltCallback

[Address Reference Count : 1]

- stm32f1xx_hal_uart.o(.text.UART_InitCallbacksToDefault)

HAL_UART_TxHalfCpltCallback (Thumb, 8 bytes, Stack size 4 bytes, stm32f1xx_hal_uart.o(.text.HAL_UART_TxHalfCpltCallback))

[Stack]

- Max Depth = 4
- Call Chain = HAL_UART_TxHalfCpltCallback

[Address Reference Count : 1]

- stm32f1xx_hal_uart.o(.text.UART_InitCallbacksToDefault)

HardFault_Handler (Thumb, 4 bytes, Stack size 0 bytes, stm32f1xx_it.o(.text.HardFault_Handler))
[Address Reference Count : 1]

- startup_stm32f103xb.o(RESET)

MX_DMA_Init (Thumb, 56 bytes, Stack size 16 bytes, dma.o(.text.MX_DMA_Init))

[Stack]

- Max Depth = 80
- Call Chain = MX_DMA_Init ⇒ HAL_NVIC_SetPriority ⇒ NVIC_EncodePriority

[Calls]

- >> HAL_NVIC_EnableIRQ
- >> HAL_NVIC_SetPriority

[Called By]

- >> main

MX_GPIO_Init (Thumb, 122 bytes, Stack size 48 bytes, gpio.o(.text.MX_GPIO_Init))

[Stack]

- Max Depth = 112
- Call Chain = MX_GPIO_Init ⇒ HAL_GPIO_Init

[Calls]

- >> HAL_GPIO_Init
- >> HAL_GPIO_WritePin

[Called By]

- >> main

MX_USART1_UART_Init (Thumb, 64 bytes, Stack size 16 bytes, usart.o(.text.MX_USART1_UART_Init))

[Stack]

- Max Depth = 64
- Call Chain = MX_USART1_UART_Init ⇒ HAL_UART_Init ⇒ UART_SetConfig ⇒ HAL_RCC_GetPCLK1Freq

[Calls]

- >> HAL_UART_Init
- >> Error_Handler

[Called By]

- >> main

MX_USART2_UART_Init (Thumb, 68 bytes, Stack size 16 bytes, usart.o(.text.MX_USART2_UART_Init))

[Stack]

- Max Depth = 64
- Call Chain = MX_USART2_UART_Init ⇒ HAL_UART_Init ⇒ UART_SetConfig ⇒ HAL_RCC_GetPCLK1Freq

[Calls]

- >> HAL_UART_Init
- >> Error_Handler

[Called By]

- >> main

MemManage_Handler (Thumb, 4 bytes, Stack size 0 bytes, stm32f1xx_it.o(.text.MemManage_Handler))
[Address Reference Count : 1]

- startup_stm32f103xb.o(RESET)

NMI_Handler (Thumb, 4 bytes, Stack size 0 bytes, stm32f1xx_it.o(.text.NMI_Handler))
[Address Reference Count : 1]

- startup_stm32f103xb.o(RESET)

PendSV_Handler (Thumb, 2 bytes, Stack size 0 bytes, stm32f1xx_it.o(.text.PendSV_Handler))
[Address Reference Count : 1]

- startup_stm32f103xb.o(RESET)

SVC_Handler (Thumb, 2 bytes, Stack size 0 bytes, stm32f1xx_it.o(.text.SVC_Handler))
[Address Reference Count : 1]

- startup_stm32f103xb.o(RESET)

SysTick_Handler (Thumb, 8 bytes, Stack size 8 bytes, stm32f1xx_it.o(.text.SysTick_Handler))

[Stack]

- Max Depth = 8
- Call Chain = SysTick_Handler

[Calls]

- >> HAL_IncTick

[Address Reference Count : 1]

- startup_stm32f103xb.o(RESET)

SystemClock_Config (Thumb, 112 bytes, Stack size 72 bytes, main.o(.text.SystemClock_Config))

[Stack]

- Max Depth = 176
- Call Chain = SystemClock_Config ⇒ HAL_RCC_ClockConfig ⇒ HAL_InitTick ⇒ HAL_NVIC_SetPriority ⇒ NVIC_EncodePriority

[Calls]

- >> __aeabi_memclr4
- >> HAL_RCC_ClockConfig
- >> Error_Handler
- >> HAL_RCC_OscConfig

[Called By]

- >> main

SystemInit (Thumb, 2 bytes, Stack size 0 bytes, system_stm32f1xx.o(.text.SystemInit))
[Address Reference Count : 1]

- startup_stm32f103xb.o(.text)

UART_InitCallbacksToDefault (Thumb, 116 bytes, Stack size 4 bytes, stm32f1xx_hal_uart.o(.text.UART_InitCallbacksToDefault))

[Stack]

- Max Depth = 4
- Call Chain = UART_InitCallbacksToDefault

[Called By]

- >> HAL_UART_Init

UART_Start_Receive_DMA (Thumb, 268 bytes, Stack size 40 bytes, stm32f1xx_hal_uart.o(.text.UART_Start_Receive_DMA))

[Stack]

- Max Depth = 88
- Call Chain = UART_Start_Receive_DMA ⇒ HAL_DMA_Start_IT ⇒ DMA_SetConfig

[Calls]

- >> HAL_DMA_Start_IT

[Called By]

- >> HAL_UARTEx_ReceiveToIdle_DMA

USART1_IRQHandler (Thumb, 16 bytes, Stack size 8 bytes, stm32f1xx_it.o(.text.USART1_IRQHandler))

[Stack]

- Max Depth = 128
- Call Chain = USART1_IRQHandler ⇒ HAL_UART_IRQHandler ⇒ HAL_DMA_Abort_IT

[Calls]

- >> HAL_UART_IRQHandler

[Address Reference Count : 1]

- startup_stm32f103xb.o(RESET)

USART2_IRQHandler (Thumb, 16 bytes, Stack size 8 bytes, stm32f1xx_it.o(.text.USART2_IRQHandler))

[Stack]

- Max Depth = 128
- Call Chain = USART2_IRQHandler ⇒ HAL_UART_IRQHandler ⇒ HAL_DMA_Abort_IT

[Calls]

- >> HAL_UART_IRQHandler

[Address Reference Count : 1]

- startup_stm32f103xb.o(RESET)

UsageFault_Handler (Thumb, 4 bytes, Stack size 0 bytes, stm32f1xx_it.o(.text.UsageFault_Handler))
[Address Reference Count : 1]

- startup_stm32f103xb.o(RESET)

data_check (Thumb, 70 bytes, Stack size 12 bytes, packet_handler.o(.text.data_check))

[Stack]

- Max Depth = 12
- Call Chain = data_check

[Called By]

- >> tx_frame_complete

lwrb_get_free (Thumb, 102 bytes, Stack size 20 bytes, lwrb.o(.text.lwrb_get_free))

[Stack]

- Max Depth = 20
- Call Chain = lwrb_get_free

[Called By]

- >> lwrb_write_ex

lwrb_get_full (Thumb, 100 bytes, Stack size 20 bytes, lwrb.o(.text.lwrb_get_full))

[Stack]

- Max Depth = 20
- Call Chain = lwrb_get_full

[Called By]

- >> send_data
- >> lwrb_read_ex

lwrb_init (Thumb, 76 bytes, Stack size 16 bytes, lwrb.o(.text.lwrb_init))

[Stack]

- Max Depth = 16
- Call Chain = lwrb_init

[Called By]

- >> packt_init

lwrb_read (Thumb, 54 bytes, Stack size 32 bytes, lwrb.o(.text.lwrb_read))

[Stack]

- Max Depth = 108
- Call Chain = lwrb_read ⇒ lwrb_read_ex ⇒ lwrb_get_full

[Calls]

- >> lwrb_read_ex

[Called By]

- >> send_data

lwrb_read_ex (Thumb, 338 bytes, Stack size 56 bytes, lwrb.o(.text.lwrb_read_ex))

[Stack]

- Max Depth = 76
- Call Chain = lwrb_read_ex ⇒ lwrb_get_full

[Calls]

- >> __aeabi_memcpy
- >> lwrb_get_full

[Called By]

- >> lwrb_read

lwrb_write (Thumb, 54 bytes, Stack size 32 bytes, lwrb.o(.text.lwrb_write))

[Stack]

- Max Depth = 108
- Call Chain = lwrb_write ⇒ lwrb_write_ex ⇒ lwrb_get_free

[Calls]

- >> lwrb_write_ex

[Called By]

- >> write2buf
- >> packet_write_rb

lwrb_write_ex (Thumb, 338 bytes, Stack size 56 bytes, lwrb.o(.text.lwrb_write_ex))

[Stack]

- Max Depth = 76
- Call Chain = lwrb_write_ex ⇒ lwrb_get_free

[Calls]

- >> __aeabi_memcpy
- >> lwrb_get_free

[Called By]

- >> lwrb_write

main (Thumb, 432 bytes, Stack size 216 bytes, main.o(.text.main))

[Stack]

- Max Depth = 392
- Call Chain = main ⇒ SystemClock_Config ⇒ HAL_RCC_ClockConfig ⇒ HAL_InitTick ⇒ HAL_NVIC_SetPriority ⇒ NVIC_EncodePriority

[Calls]

- >> sprintf
- >> serial_printf_string
- >> servo_sync_write_pos_ex
- >> servo_init
- >> MX_USART2_UART_Init
- >> MX_USART1_UART_Init
- >> MX_DMA_Init
- >> MX_GPIO_Init
- >> SystemClock_Config
- >> HAL_Init
- >> MX_NVIC_Init

[Address Reference Count : 1]

- entry9a.o(.ARM.Collect$$$$0000000B)

packet_write_rb (Thumb, 166 bytes, Stack size 16 bytes, packet_handler.o(.text.packet_write_rb))

[Stack]

- Max Depth = 124
- Call Chain = packet_write_rb ⇒ lwrb_write ⇒ lwrb_write_ex ⇒ lwrb_get_free

[Calls]

- >> lwrb_write

[Called By]

- >> servo_dma_receive_event_callback

packt_init (Thumb, 140 bytes, Stack size 32 bytes, packet_handler.o(.text.packt_init))

[Stack]

- Max Depth = 48
- Call Chain = packt_init ⇒ lwrb_init

[Calls]

- >> __aeabi_memclr4
- >> lwrb_init

[Called By]

- >> servo_init

serial_printf_string (Thumb, 48 bytes, Stack size 16 bytes, usart.o(.text.serial_printf_string))

[Stack]

- Max Depth = 112
- Call Chain = serial_printf_string ⇒ HAL_UART_Transmit ⇒ UART_WaitOnFlagUntilTimeout ⇒ UART_EndRxTransfer

[Calls]

- >> HAL_UART_Transmit

[Called By]

- >> main

servo_init (Thumb, 82 bytes, Stack size 16 bytes, hx_30hm.o(.text.servo_init))

[Stack]

- Max Depth = 64
- Call Chain = servo_init ⇒ packt_init ⇒ lwrb_init

[Calls]

- >> packt_init
- >> HAL_UART_RegisterRxEventCallback
- >> HAL_UART_RegisterCallback

[Called By]

- >> main

servo_sync_write_pos_ex (Thumb, 684 bytes, Stack size 16 bytes, hx_30hm.o(.text.servo_sync_write_pos_ex))

[Stack]

- Max Depth = 172
- Call Chain = servo_sync_write_pos_ex ⇒ sync_write ⇒ write2buf ⇒ lwrb_write ⇒ lwrb_write_ex ⇒ lwrb_get_free

[Calls]

- >> sync_write
- >> word2bytes

[Called By]

- >> main

sync_write (Thumb, 222 bytes, Stack size 16 bytes, hx_30hm.o(.text.sync_write))

[Stack]

- Max Depth = 156
- Call Chain = sync_write ⇒ write2buf ⇒ lwrb_write ⇒ lwrb_write_ex ⇒ lwrb_get_free

[Calls]

- >> send_data
- >> write2buf

[Called By]

- >> servo_sync_write_pos_ex

tx_frame_complete (Thumb, 172 bytes, Stack size 24 bytes, packet_handler.o(.text.tx_frame_complete))

[Stack]

- Max Depth = 36
- Call Chain = tx_frame_complete ⇒ data_check

[Calls]

- >> data_check

[Called By]

- >> write2buf

word2bytes (Thumb, 60 bytes, Stack size 16 bytes, packet_handler.o(.text.word2bytes))

[Stack]

- Max Depth = 16
- Call Chain = word2bytes

[Called By]

- >> servo_sync_write_pos_ex

__0sprintf (Thumb, 34 bytes, Stack size 24 bytes, printfa.o(i.__0sprintf), UNUSED)

[Calls]

- >> _sputc
- >> _printf_core

__1sprintf (Thumb, 0 bytes, Stack size 24 bytes, printfa.o(i.__0sprintf), UNUSED)

__2sprintf (Thumb, 0 bytes, Stack size 24 bytes, printfa.o(i.__0sprintf), UNUSED)

__c89sprintf (Thumb, 0 bytes, Stack size 24 bytes, printfa.o(i.__0sprintf), UNUSED)

sprintf (Thumb, 0 bytes, Stack size 24 bytes, printfa.o(i.__0sprintf))

[Stack]

- Max Depth = 24
- Call Chain = sprintf

[Called By]

- >> main

__scatterload_copy (Thumb, 14 bytes, Stack size unknown bytes, handlers.o(i.__scatterload_copy), UNUSED)

__scatterload_null (Thumb, 2 bytes, Stack size unknown bytes, handlers.o(i.__scatterload_null), UNUSED)

__scatterload_zeroinit (Thumb, 14 bytes, Stack size unknown bytes, handlers.o(i.__scatterload_zeroinit), UNUSED)

### Local Symbols

MX_NVIC_Init (Thumb, 26 bytes, Stack size 16 bytes, main.o(.text.MX_NVIC_Init))

[Stack]

- Max Depth = 80
- Call Chain = MX_NVIC_Init ⇒ HAL_NVIC_SetPriority ⇒ NVIC_EncodePriority

[Calls]

- >> HAL_NVIC_EnableIRQ
- >> HAL_NVIC_SetPriority

[Called By]

- >> main

UART_SetConfig (Thumb, 186 bytes, Stack size 24 bytes, stm32f1xx_hal_uart.o(.text.UART_SetConfig))

[Stack]

- Max Depth = 32
- Call Chain = UART_SetConfig ⇒ HAL_RCC_GetPCLK1Freq

[Calls]

- >> HAL_RCC_GetPCLK1Freq
- >> HAL_RCC_GetPCLK2Freq

[Called By]

- >> HAL_UART_Init

UART_WaitOnFlagUntilTimeout (Thumb, 218 bytes, Stack size 32 bytes, stm32f1xx_hal_uart.o(.text.UART_WaitOnFlagUntilTimeout))

[Stack]

- Max Depth = 48
- Call Chain = UART_WaitOnFlagUntilTimeout ⇒ UART_EndRxTransfer

[Calls]

- >> HAL_GetTick
- >> UART_EndRxTransfer

[Called By]

- >> HAL_UART_Transmit

UART_EndRxTransfer (Thumb, 148 bytes, Stack size 16 bytes, stm32f1xx_hal_uart.o(.text.UART_EndRxTransfer))

[Stack]

- Max Depth = 16
- Call Chain = UART_EndRxTransfer

[Called By]

- >> UART_DMAError
- >> UART_WaitOnFlagUntilTimeout
- >> HAL_UART_IRQHandler

UART_DMAError (Thumb, 124 bytes, Stack size 24 bytes, stm32f1xx_hal_uart.o(.text.UART_DMAError))

[Stack]

- Max Depth = 40
- Call Chain = UART_DMAError ⇒ UART_EndRxTransfer

[Calls]

- >> UART_EndTxTransfer
- >> UART_EndRxTransfer

[Address Reference Count : 1]

- stm32f1xx_hal_uart.o(.text.UART_Start_Receive_DMA)

UART_EndTxTransfer (Thumb, 54 bytes, Stack size 8 bytes, stm32f1xx_hal_uart.o(.text.UART_EndTxTransfer))

[Stack]

- Max Depth = 8
- Call Chain = UART_EndTxTransfer

[Called By]

- >> UART_DMAError

UART_DMAReceiveCplt (Thumb, 244 bytes, Stack size 32 bytes, stm32f1xx_hal_uart.o(.text.UART_DMAReceiveCplt))

[Stack]

- Max Depth = 32
- Call Chain = UART_DMAReceiveCplt

[Address Reference Count : 1]

- stm32f1xx_hal_uart.o(.text.UART_Start_Receive_DMA)

UART_DMARxHalfCplt (Thumb, 52 bytes, Stack size 16 bytes, stm32f1xx_hal_uart.o(.text.UART_DMARxHalfCplt))

[Stack]

- Max Depth = 16
- Call Chain = UART_DMARxHalfCplt

[Address Reference Count : 1]

- stm32f1xx_hal_uart.o(.text.UART_Start_Receive_DMA)

UART_Receive_IT (Thumb, 362 bytes, Stack size 32 bytes, stm32f1xx_hal_uart.o(.text.UART_Receive_IT))

[Stack]

- Max Depth = 32
- Call Chain = UART_Receive_IT

[Called By]

- >> HAL_UART_IRQHandler

UART_DMAAbortOnError (Thumb, 32 bytes, Stack size 16 bytes, stm32f1xx_hal_uart.o(.text.UART_DMAAbortOnError))

[Stack]

- Max Depth = 16
- Call Chain = UART_DMAAbortOnError

[Address Reference Count : 1]

- stm32f1xx_hal_uart.o(.text.HAL_UART_IRQHandler)

UART_Transmit_IT (Thumb, 148 bytes, Stack size 12 bytes, stm32f1xx_hal_uart.o(.text.UART_Transmit_IT))

[Stack]

- Max Depth = 12
- Call Chain = UART_Transmit_IT

[Called By]

- >> HAL_UART_IRQHandler

UART_EndTransmit_IT (Thumb, 38 bytes, Stack size 16 bytes, stm32f1xx_hal_uart.o(.text.UART_EndTransmit_IT))

[Stack]

- Max Depth = 16
- Call Chain = UART_EndTransmit_IT

[Called By]

- >> HAL_UART_IRQHandler

RCC_Delay (Thumb, 58 bytes, Stack size 8 bytes, stm32f1xx_hal_rcc.o(.text.RCC_Delay))

[Stack]

- Max Depth = 8
- Call Chain = RCC_Delay

[Called By]

- >> HAL_RCC_OscConfig

DMA_SetConfig (Thumb, 80 bytes, Stack size 16 bytes, stm32f1xx_hal_dma.o(.text.DMA_SetConfig))

[Stack]

- Max Depth = 16
- Call Chain = DMA_SetConfig

[Called By]

- >> HAL_DMA_Start_IT

__NVIC_SetPriorityGrouping (Thumb, 60 bytes, Stack size 12 bytes, stm32f1xx_hal_cortex.o(.text.__NVIC_SetPriorityGrouping))

[Stack]

- Max Depth = 12
- Call Chain = __NVIC_SetPriorityGrouping

[Called By]

- >> HAL_NVIC_SetPriorityGrouping

__NVIC_GetPriorityGrouping (Thumb, 16 bytes, Stack size 0 bytes, stm32f1xx_hal_cortex.o(.text.__NVIC_GetPriorityGrouping))

[Called By]

- >> HAL_NVIC_SetPriority

NVIC_EncodePriority (Thumb, 108 bytes, Stack size 32 bytes, stm32f1xx_hal_cortex.o(.text.NVIC_EncodePriority))

[Stack]

- Max Depth = 32
- Call Chain = NVIC_EncodePriority

[Called By]

- >> HAL_NVIC_SetPriority

__NVIC_SetPriority (Thumb, 66 bytes, Stack size 8 bytes, stm32f1xx_hal_cortex.o(.text.__NVIC_SetPriority))

[Stack]

- Max Depth = 8
- Call Chain = __NVIC_SetPriority

[Called By]

- >> SysTick_Config
- >> HAL_NVIC_SetPriority

__NVIC_EnableIRQ (Thumb, 48 bytes, Stack size 4 bytes, stm32f1xx_hal_cortex.o(.text.__NVIC_EnableIRQ))

[Stack]

- Max Depth = 4
- Call Chain = __NVIC_EnableIRQ

[Called By]

- >> HAL_NVIC_EnableIRQ

SysTick_Config (Thumb, 82 bytes, Stack size 16 bytes, stm32f1xx_hal_cortex.o(.text.SysTick_Config))

[Stack]

- Max Depth = 24
- Call Chain = SysTick_Config ⇒ __NVIC_SetPriority

[Calls]

- >> __NVIC_SetPriority

[Called By]

- >> HAL_SYSTICK_Config

tramsmit_data (Thumb, 32 bytes, Stack size 24 bytes, packet_handler.o(.text.tramsmit_data))

[Stack]

- Max Depth = 120
- Call Chain = tramsmit_data ⇒ HAL_UART_Transmit ⇒ UART_WaitOnFlagUntilTimeout ⇒ UART_EndRxTransfer

[Calls]

- >> HAL_UART_Transmit

[Address Reference Count : 1]

- packet_handler.o(.text.packt_init)

receive_dma_data (Thumb, 22 bytes, Stack size 16 bytes, packet_handler.o(.text.receive_dma_data))

[Stack]

- Max Depth = 136
- Call Chain = receive_dma_data ⇒ HAL_UARTEx_ReceiveToIdle_DMA ⇒ UART_Start_Receive_DMA ⇒ HAL_DMA_Start_IT ⇒ DMA_SetConfig

[Calls]

- >> HAL_UARTEx_ReceiveToIdle_DMA

[Address Reference Count : 1]

- packet_handler.o(.text.packt_init)

servo_uart_rx_error_callblack (Thumb, 24 bytes, Stack size 16 bytes, hx_30hm.o(.text.servo_uart_rx_error_callblack))

[Stack]

- Max Depth = 16
- Call Chain = servo_uart_rx_error_callblack

[Address Reference Count : 1]

- hx_30hm.o(.text.servo_init)

servo_dma_receive_event_callback (Thumb, 76 bytes, Stack size 16 bytes, hx_30hm.o(.text.servo_dma_receive_event_callback))

[Stack]

- Max Depth = 140
- Call Chain = servo_dma_receive_event_callback ⇒ packet_write_rb ⇒ lwrb_write ⇒ lwrb_write_ex ⇒ lwrb_get_free

[Calls]

- >> packet_write_rb
- >> HAL_UARTEx_GetRxEventType

[Address Reference Count : 1]

- hx_30hm.o(.text.servo_init)

write2buf (Thumb, 152 bytes, Stack size 32 bytes, hx_30hm.o(.text.write2buf))

[Stack]

- Max Depth = 140
- Call Chain = write2buf ⇒ lwrb_write ⇒ lwrb_write_ex ⇒ lwrb_get_free

[Calls]

- >> tx_frame_complete
- >> lwrb_write

[Called By]

- >> sync_write

send_data (Thumb, 166 bytes, Stack size 16 bytes, hx_30hm.o(.text.send_data))

[Stack]

- Max Depth = 124
- Call Chain = send_data ⇒ lwrb_read ⇒ lwrb_read_ex ⇒ lwrb_get_full

[Calls]

- >> lwrb_get_full
- >> lwrb_read

[Called By]

- >> sync_write

_fp_digits (Thumb, 366 bytes, Stack size 64 bytes, printfa.o(i._fp_digits), UNUSED)

[Calls]

- >> __aeabi_uldivmod
- >> __aeabi_dmul
- >> __aeabi_ddiv
- >> __aeabi_dadd
- >> __aeabi_d2ulz
- >> __aeabi_cdrcmple

[Called By]

- >> _printf_core

_printf_core (Thumb, 1744 bytes, Stack size 136 bytes, printfa.o(i._printf_core), UNUSED)

[Calls]

- >> _printf_pre_padding
- >> _printf_post_padding
- >> _fp_digits
- >> __aeabi_uldivmod
- >> __aeabi_uidivmod

[Called By]

- >> __0sprintf

_printf_post_padding (Thumb, 36 bytes, Stack size 24 bytes, printfa.o(i._printf_post_padding), UNUSED)

[Called By]

- >> _printf_core

_printf_pre_padding (Thumb, 46 bytes, Stack size 24 bytes, printfa.o(i._printf_pre_padding), UNUSED)

[Called By]

- >> _printf_core

_sputc (Thumb, 10 bytes, Stack size 0 bytes, printfa.o(i._sputc))

[Called By]

- >> __0sprintf

[Address Reference Count : 1]

- printfa.o(i.__0sprintf)

### Undefined Global Symbols

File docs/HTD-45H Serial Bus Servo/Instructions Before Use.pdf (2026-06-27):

# Instructions Before Use

1) Bus Servo Control.exe is PC software of Bus servo controller. 2) Bus Servo Terminal is the parameter setting software of LX-224HV servo.
3) Before using the servo controller, please set the parameters and ID of the servo with the servo debug board (BusLinker). In general, you only need to set the ID.

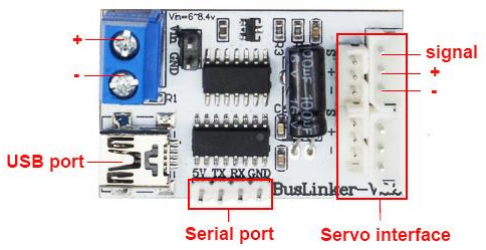
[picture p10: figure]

4) The servo controller can be used to control the servos after the servo ID number being set.

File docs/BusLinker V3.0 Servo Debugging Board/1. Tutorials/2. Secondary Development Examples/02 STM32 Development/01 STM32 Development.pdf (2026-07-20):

# 3. STM32 Development

## 3. STM32 Development

3.1 Getting Started 3.1.1 Wiring Instruction 3.1.2 Environment Configuration 3.2 Development Example 3.2.1 Reading the Servo Status 3.2.2 Reading the Servo Status 3.2.3 Servo Movement Control in Write Mode 3.2.4 Reading the Servo Status 3.2.5 Servo Movement Control in SyncWrite Mode 3.2.6 Reading the Servo Status

# 3.1 Getting Started

# 3.1.1 Wiring Instruction

This example uses the STM32 controller for development, with power, program download, and debug data handled via the data cable. The bus servo is connected to the debugging board, which is powered by an 11.1 V lithium battery. The STM32F103RBT6 microcontroller and the debugging board are then connected through the serial pins using Dupont wires.

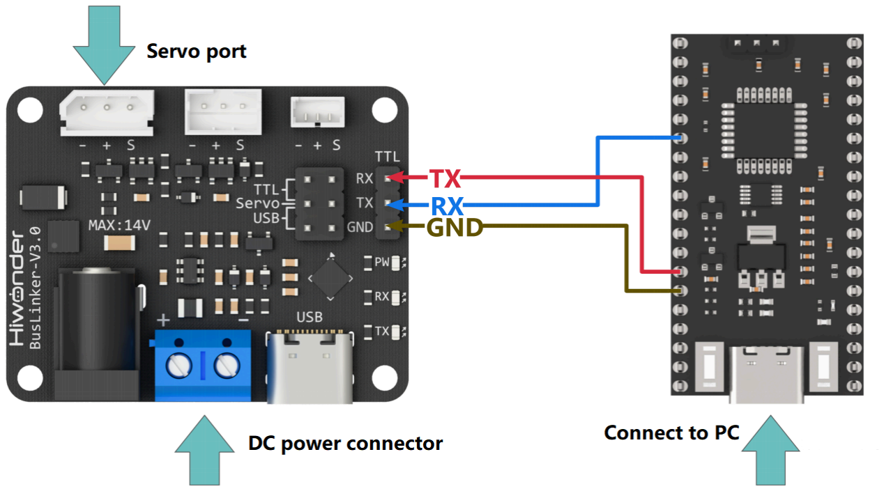
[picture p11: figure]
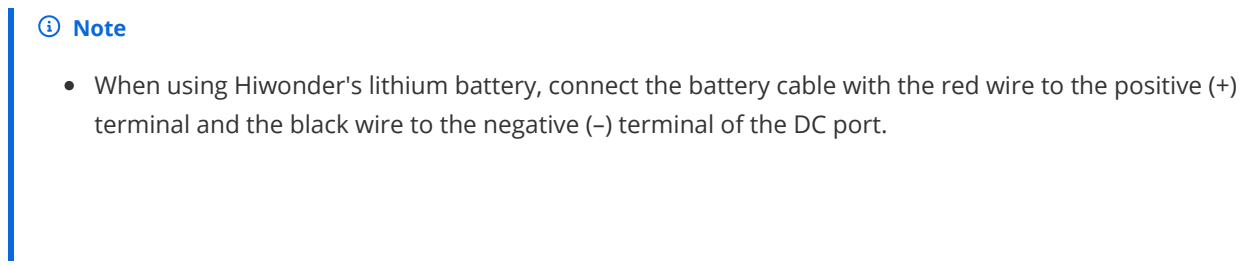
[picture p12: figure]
Note

When using Hiwonder's lithium battery, connect the battery cable with the red wire to the positive (+) terminal and the black wire to the negative (–) terminal of the DC port.

Before connecting the battery cables, make sure they are not already attached to the lithium battery. This prevents the risk of a short circuit caused by accidental contact between the positive and

# 3.1.2 Environment Configuration

Install Keil MDK IDE software on PC. The software package is stored in 2. Softwares (https://drive.google.com/drive/folders/14k_MJ6fFkFPAEBaWcQeiwZTW2JwAIgTw) \ (https://drive.google.com/drive/folders/14k_MJ6fFkFPAEBaWcQeiwZTW2JwAIgTw) STM32 Programming Software. (https://drive.google.com/drive/folders/14k_MJ6fFkFPAEBaWcQeiwZTW2JwAIgTw) For the detailed operations of Keil MDK IDE, please refer to the relevant tutorials.

## 3.1.2.1 Program Upload

1. Connect the controller to the computer using a USB cable.
2. Double-click to open the STM32 serial programming software FlyMcu.
3. Click the ... icon and select the HEX file to be programmed from the path: Serial_Servo\MDK-ARM\Serial_Servo.

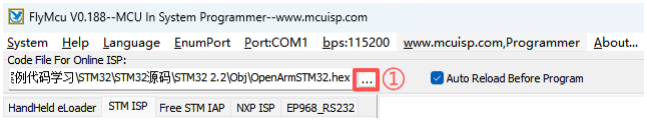
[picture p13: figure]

4. At position ② in the figure, select the serial port corresponding to the controller. At ③, select a baud rate of 115200. Configure ④ and ⑤ according to the options shown in the figure.

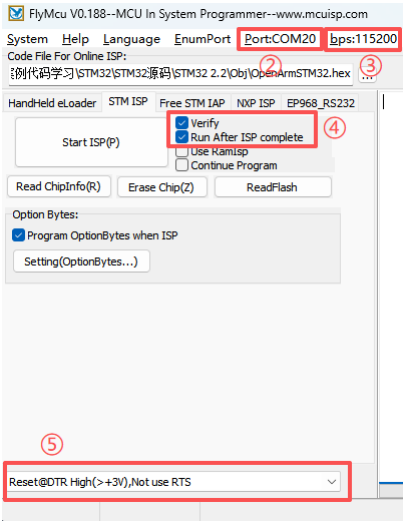
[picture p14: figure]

5. Click Start ISP(P), then press the RST button on the controller. The program will automatically begin downloading. Once the following content appears in the log output on the right, the program download will be complete.

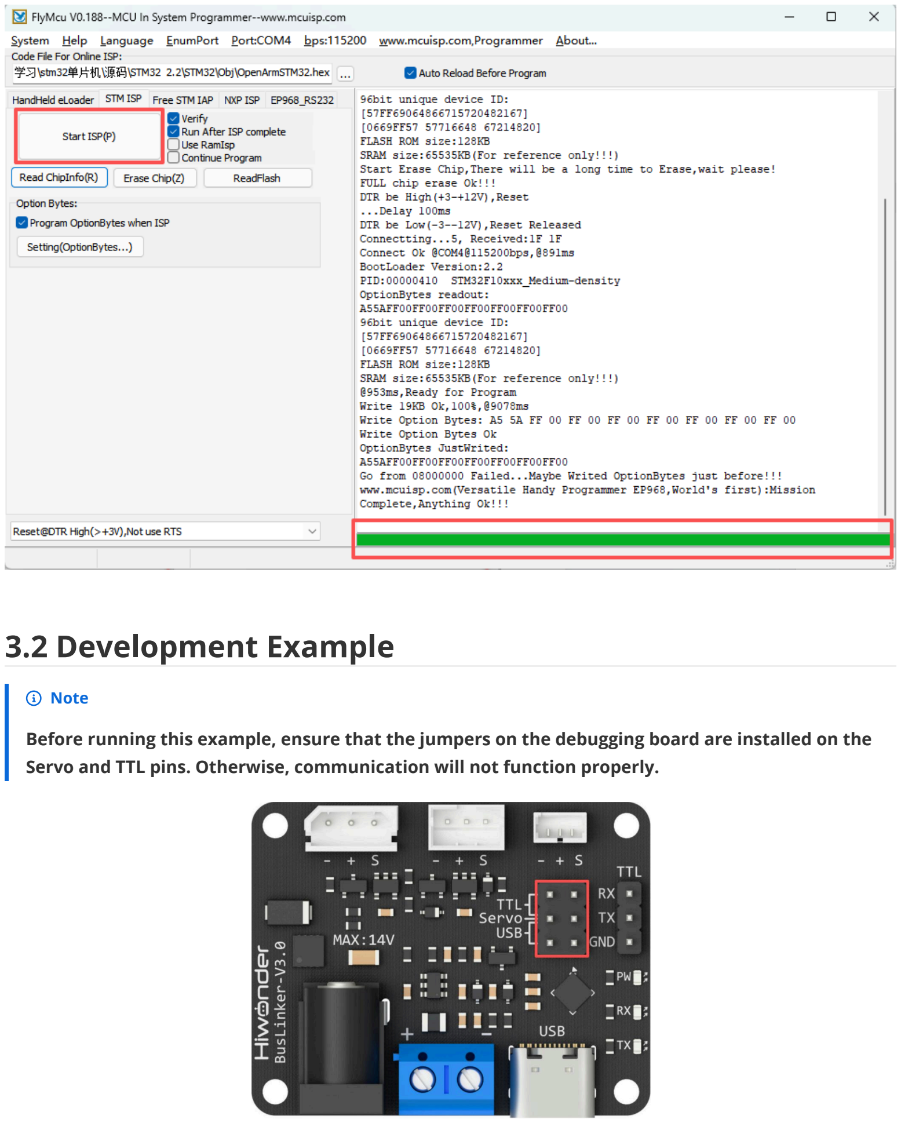
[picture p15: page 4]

# 3.2 Development Example

## Note

Before running this example, ensure that the jumpers on the debugging board are installed on the Servo and TTL pins. Otherwise, communication will not function properly.

# 3.2.1 Reading the Servo Status

This example displays the bus servo status information through the serial debug assistant window.

## 3.2.1.1 Run Program

Double-click the Serial_Servo.uvprojx file located at the STM32 Development (https://drive.google.com/drive/folders/15F7xqqgLFG87yAPyvIzhmUMEoYqZEltF) \ (https://drive.google.com/drive/folders/15F7xqqgLFG87yAPyvIzhmUMEoYqZEltF) Program (https://drive.google.com/drive/folders/15F7xqqgLFG87yAPyvIzhmUMEoYqZEltF) \ (https://drive.google.com/drive/folders/15F7xqqgLFG87yAPyvIzhmUMEoYqZEltF) Serial_Servo (https://drive.google.com/drive/folders/15F7xqqgLFG87yAPyvIzhmUMEoYqZEltF) \ (https://drive.google.com/drive/folders/15F7xqqgLFG87yAPyvIzhmUMEoYqZEltF) MDK-ARM (https://drive.google.com/drive/folders/15F7xqqgLFG87yAPyvIzhmUMEoYqZEltF) folder. Change the value of the exp macro definition in the main.c file to 1, then compile the project.

Connect the STM32F103RBT6 microcontroller to the computer and upload the compiled HEX file to the microcontroller.

## 3.2.1.2 Program Outcome

After running the program, open the serial debug assistant, select the corresponding COM port, set the baud rate to 115200, and open the port. The debug assistant prints the sent data packets and the servo status information, which corresponds to the data frames returned by the servo.

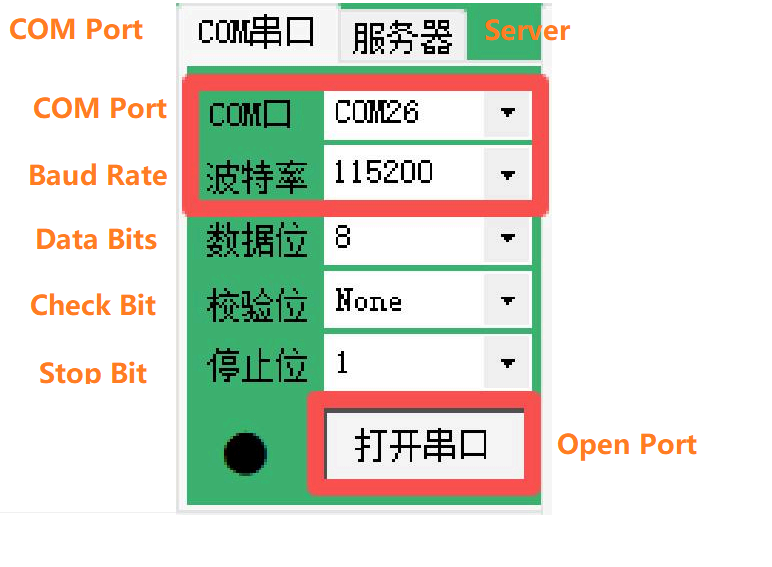
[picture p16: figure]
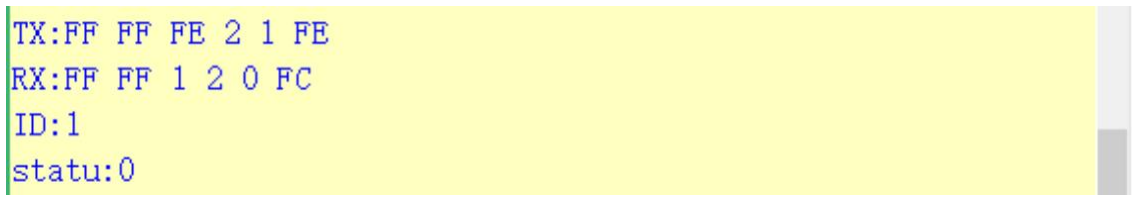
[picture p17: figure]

## 3.2.1.3 Program Brief Analysis

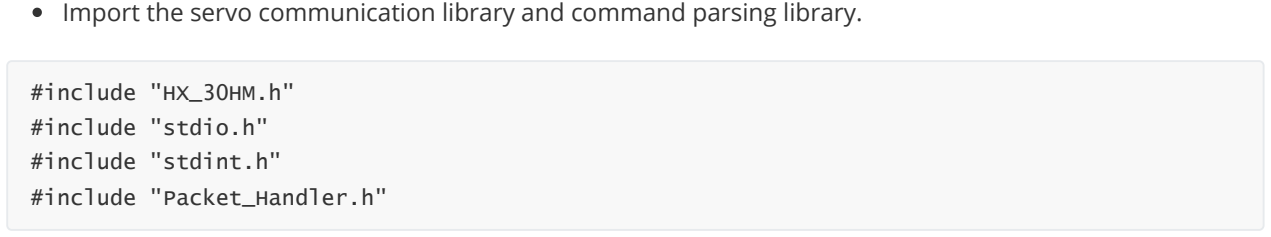
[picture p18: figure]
#include "HX_30HM.h"; #include "stdio.h"; #include "stdint.h"; #include "Packet_Handler.h"

Import the servo communication library and command parsing library.

Define the parameters to send and receive.

Define two hardware serial ports: Serial 1 is used to print debug information to the PC serial debug assistant at a baud rate of 115200. Serial 2 is used for communication with the debugging board at a baud rate of 1000000.

The ping function broadcasts to search for servos, prints the detected ID numbers, and returns the working status of the servo.

ServoStatus_t status;

int16_t write_pos = 4096;
int16_t read_pos = 4096;

int16_t write_pos_offset = 100; int16_t read_pos_offset;

uint8_t write_acc = 100;

int16_t write_speed = 1000; int16_t read_speed;

int16_t write_pwm_speed = 1000;

uint16_t write_torque = 1000;

int16_t sync_write1[2][4] = {{1, 0, 1000, 4095}, {2, 0, 1000, 4095}}; int16_t sync_write2[2][4] = {{1, 0, 1000, 0}, {2, 0, 1000, 0}}; uint8_t read_id[] = {1, 2};
int16_t sync_read_data[2][5];

uint8_t temp;
uint8_t vol;
uint16_t cur;
int16_t read_load;
uint8_t moving_status;

#include "HX_30HM.h"

/* Initialize all configured peripherals */ MX_GPIO_Init();
MX_DMA_Init();
MX_USART1_UART_Init();
MX_USART2_UART_Init();

/* Initialize interrupts */ MX_NVIC_Init();
/* USER CODE BEGIN 2 */
servo_init();

Print the sent data packets and the servo response frames to the PC serial debug assistant.

Print the returned servo ID and operating status parameters to the PC serial debug assistant.

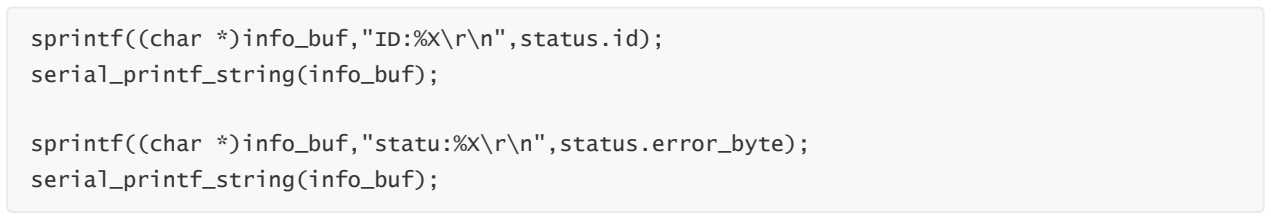
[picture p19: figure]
sprintf((char *)info_buf,"ID:%X\r\n",status.id);; serial_printf_string(info_buf);; sprintf((char *)info_buf,"statu:%X\r\n",status.error_byte);

# 3.2.2 Reading the Servo Status

This example displays the current position information of the bus servo through the serial debug assistant window.

## 3.2.2.1 Run Program

Double-click the Serial_Servo.uvprojx file located at the STM32 Development (https://drive.google.com/drive/folders/15F7xqqgLFG87yAPyvIzhmUMEoYqZEltF) \ (https://drive.google.com/drive/folders/15F7xqqgLFG87yAPyvIzhmUMEoYqZEltF) Program (https://drive.google.com/drive/folders/15F7xqqgLFG87yAPyvIzhmUMEoYqZEltF) \ (https://drive.google.com/drive/folders/15F7xqqgLFG87yAPyvIzhmUMEoYqZEltF) Serial_Servo (https://drive.google.com/drive/folders/15F7xqqgLFG87yAPyvIzhmUMEoYqZEltF) \ (https://drive.google.com/drive/folders/15F7xqqgLFG87yAPyvIzhmUMEoYqZEltF) MDK-ARM (https://drive.google.com/drive/folders/15F7xqqgLFG87yAPyvIzhmUMEoYqZEltF) folder. Change the value of the exp macro definition in the main.c file to 1, then compile the project.

Connect the STM32F103RBT6 microcontroller to the computer and upload the compiled HEX file to the microcontroller.

## 3.2.2.2 Program Outcome

sprintf((char *)info_buf,"TX:%X %X %X %X %X %X\r\n",servo_packet.tx.header_1,\ servo_packet.tx.header_2,\
servo_packet.tx.elements.id,\
servo_packet.tx.elements.length,\
servo_packet.tx.elements.cmd,\

servo_packet.tx.elements.args[servo_packet.tx.elements.length - 2]\ );
serial_printf_string(info_buf);

sprintf((char *)info_buf,"RX:%X %X %X %X %X %X\r\n",servo_packet.rx.header_1,\ servo_packet.rx.header_2,\
servo_packet.rx.elements.id,\
servo_packet.rx.elements.length,\
servo_packet.rx.elements.cmd,\

servo_packet.rx.elements.args[servo_packet.rx.elements.length - 2]\ );
serial_printf_string(info_buf);

After running the program, the serial debug assistant prints the sent data packets and the current position of the servo, which corresponds to the data frames returned by the servo.

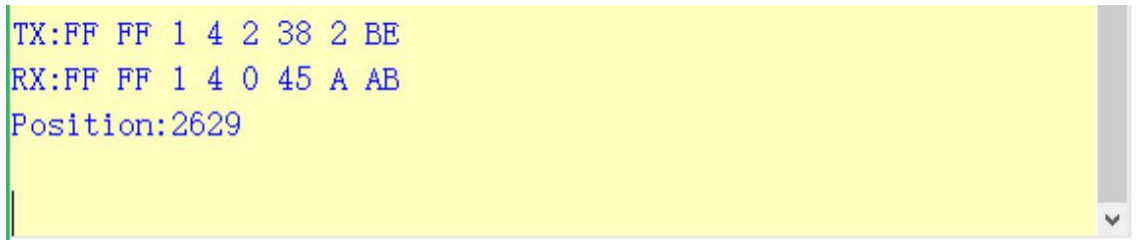
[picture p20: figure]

## 3.2.2.3 Program Brief Analysis

Import the servo communication library and command parsing library.

Define the parameters to send and receive.

#include "HX_30HM.h"

#include "stdio.h"

#include "stdint.h"

#include "Packet_Handler.h"

ServoStatus_t status;

int16_t write_pos = 4096;
int16_t read_pos = 4096;

int16_t write_pos_offset = 100; int16_t read_pos_offset;

uint8_t write_acc = 100;

int16_t write_speed = 1000; int16_t read_speed;

int16_t write_pwm_speed = 1000;

uint16_t write_torque = 1000;

int16_t sync_write1[2][4] = {{1, 0, 1000, 4095}, {2, 0, 1000, 4095}}; int16_t sync_write2[2][4] = {{1, 0, 1000, 0}, {2, 0, 1000, 0}}; uint8_t read_id[] = {1, 2};
int16_t sync_read_data[2][5];

uint8_t temp;
uint8_t vol;
uint16_t cur;
int16_t read_load;
uint8_t moving_status;

Define two hardware serial ports: Serial 1 is used to print debug information to the PC serial debug assistant at a baud rate of 115200. Serial 2 is used for communication with the debugging board at a baud rate of 1000000.

The read_pos function reads the current position value of servo ID 1.

Print the sent data packets and the servo response frames to the PC serial debug assistant.

Print the returned current position values of the servo to the PC serial debug assistant.

#include "HX_30HM.h"

/* Initialize all configured peripherals */ MX_GPIO_Init();
MX_DMA_Init();
MX_USART1_UART_Init();
MX_USART2_UART_Init();

/* Initialize interrupts */ MX_NVIC_Init();
/* USER CODE BEGIN 2 */
servo_init();

status = servo_read_pos(1, &read_pos);

sprintf((char *)info_buf,"TX:%X %X %X %X %X %X\r\n",servo_packet.tx.header_1,\ servo_packet.tx.header_2,\
servo_packet.tx.elements.id,\
servo_packet.tx.elements.length,\
servo_packet.tx.elements.cmd,\

servo_packet.tx.elements.args[servo_packet.tx.elements.length - 2]\ );
serial_printf_string(info_buf);

sprintf((char *)info_buf,"RX:%X %X %X %X %X %X\r\n",servo_packet.rx.header_1,\ servo_packet.rx.header_2,\
servo_packet.rx.elements.id,\
servo_packet.rx.elements.length,\
servo_packet.rx.elements.cmd,\

servo_packet.rx.elements.args[servo_packet.rx.elements.length - 2]\ );
serial_printf_string(info_buf);

sprintf((char *)info_buf,"Position:%hu\r\n",read_pos); serial_printf_string(info_buf);

# 3.2.3 Servo Movement Control in Write Mode

## 3.2.3.1 Run Program

Double-click the Serial_Servo.uvprojx file located at the STM32 Development (https://drive.google.com/drive/folders/15F7xqqgLFG87yAPyvIzhmUMEoYqZEltF) \ (https://drive.google.com/drive/folders/15F7xqqgLFG87yAPyvIzhmUMEoYqZEltF) Program (https://drive.google.com/drive/folders/15F7xqqgLFG87yAPyvIzhmUMEoYqZEltF) \ (https://drive.google.com/drive/folders/15F7xqqgLFG87yAPyvIzhmUMEoYqZEltF) Serial_Servo (https://drive.google.com/drive/folders/15F7xqqgLFG87yAPyvIzhmUMEoYqZEltF) \ (https://drive.google.com/drive/folders/15F7xqqgLFG87yAPyvIzhmUMEoYqZEltF) MDK-ARM (https://drive.google.com/drive/folders/15F7xqqgLFG87yAPyvIzhmUMEoYqZEltF) folder. Change the value of the exp macro definition in the main.c file to 1, then compile the project.

Connect the STM32F103RBT6 microcontroller to the computer and upload the compiled HEX file to the microcontroller.

## 3.2.3.2 Program Outcome

After running the program, the serial debugger prints the sent data packets and the data frames returned by the servo. The servo with the specified ID moves to the target position according to the configured parameters.

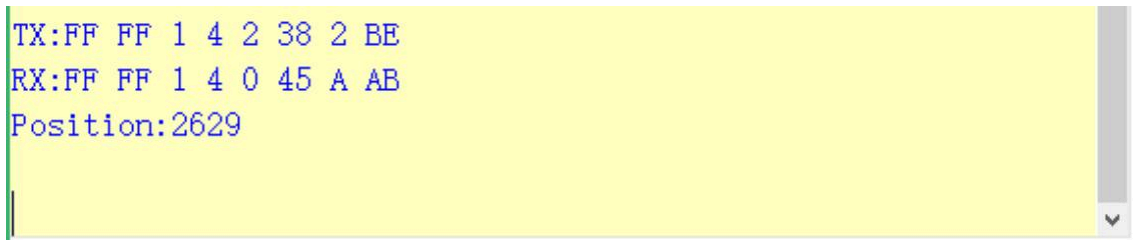
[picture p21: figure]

## 3.2.3.3 Program Brief Analysis

Import the servo communication library and command parsing library.

Define the parameters to send and receive.

#include "HX_30HM.h"

#include "stdio.h"

#include "stdint.h"

#include "Packet_Handler.h"

ServoStatus_t status;

int16_t write_pos = 4096;
int16_t read_pos = 4096;

int16_t write_pos_offset = 100; int16_t read_pos_offset;

uint8_t write_acc = 100;

int16_t write_speed = 1000; int16_t read_speed;

int16_t write_pwm_speed = 1000;

Define two hardware serial ports: Serial 1 is used to print debug information to the PC serial debug assistant at a baud rate of 115200. Serial 2 is used for communication with the debugging board at a baud rate of 1000000.

The write_pos function sets the target position of servo ID 1, and the servo moves to that position.

Print the sent data packets and the servo response frames to the PC serial debug assistant.

uint16_t write_torque = 1000;

int16_t sync_write1[2][4] = {{1, 0, 1000, 4095}, {2, 0, 1000, 4095}}; int16_t sync_write2[2][4] = {{1, 0, 1000, 0}, {2, 0, 1000, 0}}; uint8_t read_id[] = {1, 2};
int16_t sync_read_data[2][5];

uint8_t temp;
uint8_t vol;
uint16_t cur;
int16_t read_load;
uint8_t moving_status;

#include "HX_30HM.h"

/* Initialize all configured peripherals */ MX_GPIO_Init();
MX_DMA_Init();
MX_USART1_UART_Init();
MX_USART2_UART_Init();

/* Initialize interrupts */ MX_NVIC_Init();
/* USER CODE BEGIN 2 */
servo_init();

status = servo_write_pos(1, write_pos);

sprintf((char *)info_buf,"TX:%X %X %X %X %X %X\r\n",servo_packet.tx.header_1,\ servo_packet.tx.header_2,\
servo_packet.tx.elements.id,\
servo_packet.tx.elements.length,\
servo_packet.tx.elements.cmd,\

servo_packet.tx.elements.args[servo_packet.tx.elements.length - 2]\ );
serial_printf_string(info_buf);

sprintf((char *)info_buf,"RX:%X %X %X %X %X %X\r\n",servo_packet.rx.header_1,\ servo_packet.rx.header_2,\
servo_packet.rx.elements.id,\
servo_packet.rx.elements.length,\
servo_packet.rx.elements.cmd,\

Print the set target position values of the servo to the PC serial debug assistant.

# 3.2.4 Reading the Servo Status

## 3.2.4.1 Run Program

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

Connect the STM32F103RBT6 microcontroller to the computer and upload the compiled HEX file to the microcontroller.

## 3.2.4.2 Program Outcome

After running the program, the serial debugger prints the sent data packets and the data frames returned by the servo. The servo with the specified ID moves to the target position according to the configured parameters.

## 3.2.4.3 Program Brief Analysis

Import the servo communication library and command parsing library.

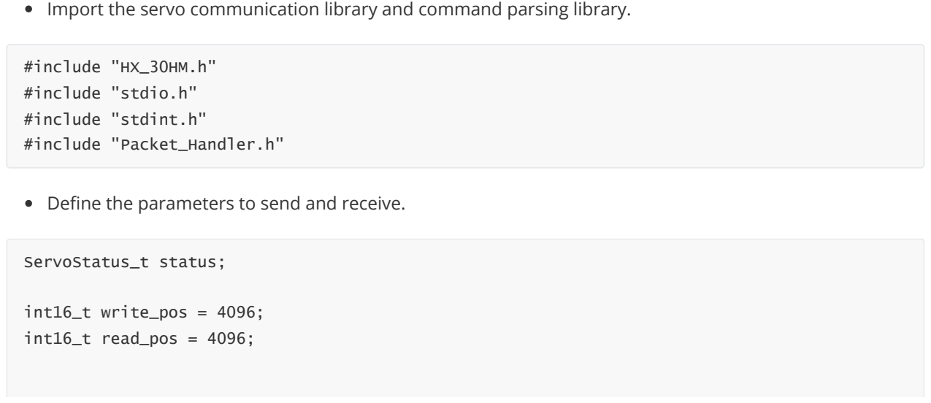
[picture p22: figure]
#include "HX_30HM.h"; #include "stdio.h"; #include "stdint.h"; #include "Packet_Handler.h"; ServoStatus_t status;; int16_t write_pos = 4096;; int16_t read_pos = 4096;

Define the parameters to send and receive.

servo_packet.rx.elements.args[servo_packet.rx.elements.length - 2]\ );
serial_printf_string(info_buf);

sprintf((char *)info_buf,"Position:%hu\r\n",read_pos); serial_printf_string(info_buf);

The write_reg_pos_ex function writes the acceleration, speed, and position information to the specified register of servo ID 1 without executing immediately. Execution is deferred and requires calling the
reg_action function.

Print the sent data packets and the servo response frames to the PC serial debug assistant.

int16_t write_pos_offset = 100; int16_t read_pos_offset;

uint8_t write_acc = 100;

int16_t write_speed = 1000; int16_t read_speed;

int16_t write_pwm_speed = 1000;

uint16_t write_torque = 1000;

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

uint8_t temp;
uint8_t vol;
uint16_t cur;
int16_t read_load;
uint8_t moving_status;

status = servo_write_reg_pos_ex(1, write_acc, write_speed, write_pos);

sprintf((char *)info_buf,"TX:%X %X %X %X %X %X %X %X %X %X %X %X %X %X %X\r\n",servo_packet.tx.header_1,\
servo_packet.tx.header_2,\
servo_packet.tx.elements.id,\
servo_packet.tx.elements.length,\ servo_packet.tx.elements.cmd,\ servo_packet.tx.elements.args[0],\ servo_packet.tx.elements.args[1],\ servo_packet.tx.elements.args[2],\ servo_packet.tx.elements.args[3],\ servo_packet.tx.elements.args[4],\ servo_packet.tx.elements.args[5],\ servo_packet.tx.elements.args[6],\ servo_packet.tx.elements.args[7],\ servo_packet.tx.elements.args[8],\ servo_packet.tx.elements.args[servo_packet.tx.elements.length - 2]\ );
serial_printf_string(info_buf);

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

After calling reg_action , the servo executes the previously written write_reg_pos_ex command and moves accordingly.

Print the sent data packets and the servo response frames to the PC serial debug assistant.

Print the set acceleration, speed, and position parameters to the PC serial debug assistant.

# 3.2.5 Servo Movement Control in SyncWrite Mode

## 3.2.5.1 Run Program

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

servo_packet.rx.elements.id,\
servo_packet.rx.elements.length,\
servo_packet.rx.elements.cmd,\ servo_packet.rx.elements.args[servo_packet.rx.elements.length - 2]\ );
serial_printf_string(info_buf);

status = servo_reg_action(1);

sprintf((char *)info_buf,"TX:%X %X %X %X %X %X\r\n",servo_packet.tx.header_1,\ servo_packet.tx.header_2,\
servo_packet.tx.elements.id,\
servo_packet.tx.elements.length,\
servo_packet.tx.elements.cmd,\ servo_packet.tx.elements.args[servo_packet.tx.elements.length - 2]\ );
serial_printf_string(info_buf);

sprintf((char *)info_buf,"RX:%X %X %X %X %X %X\r\n",servo_packet.rx.header_1,\ servo_packet.rx.header_2,\
servo_packet.rx.elements.id,\
servo_packet.rx.elements.length,\
servo_packet.rx.elements.cmd,\ servo_packet.rx.elements.args[servo_packet.rx.elements.length - 2]\ );
serial_printf_string(info_buf);

Connect the STM32F103RBT6 microcontroller to the computer and upload the compiled HEX file to the microcontroller.

## 3.2.5.2 Program Outcome

After running the program, the serial debugger prints the sent data packets. The servos with the specified IDs move to the target positions according to the configured parameters.

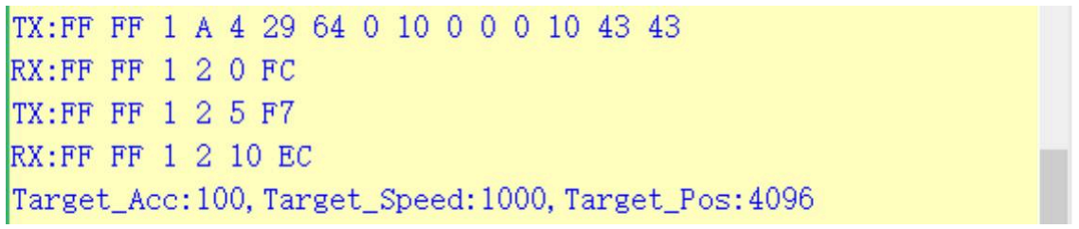
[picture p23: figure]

## 3.2.5.3 Program Brief Analysis

Import the servo communication library and command parsing library.

Define the parameters to send and receive.

#include "HX_30HM.h"

#include "stdio.h"

#include "stdint.h"

#include "Packet_Handler.h"

ServoStatus_t status;

int16_t write_pos = 4096;
int16_t read_pos = 4096;

int16_t write_pos_offset = 100; int16_t read_pos_offset;

uint8_t write_acc = 100;

int16_t write_speed = 1000; int16_t read_speed;

int16_t write_pwm_speed = 1000;

uint16_t write_torque = 1000;

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

uint8_t temp;
uint8_t vol;
uint16_t cur;
int16_t read_load;

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

The sync_write_pos_ex function sets the acceleration, speed, and position information for servo IDs 1 and 2, and the servos move to the specified positions.

Print the sent data packets to the PC serial debug assistant.

#include "HX_30HM.h"

/* Initialize all configured peripherals */ MX_GPIO_Init();
MX_DMA_Init();
MX_USART1_UART_Init();
MX_USART2_UART_Init();

/* Initialize interrupts */ MX_NVIC_Init();
/* USER CODE BEGIN 2 */
servo_init();

// Write acceleration, speed, and position information to servo 1 and 2 simultaneously status = servo_sync_write_pos_ex(sync_write1, 2);

sprintf((char *)info_buf,"TX:%X %X %X %X %X %X %X %X %X %X %X %X %X %X %X %X %X %X %X %X %X\r\n",servo_packet.tx.header_1,\
servo_packet.tx.header_2,\
servo_packet.tx.elements.id,\
servo_packet.tx.elements.length,\ servo_packet.tx.elements.cmd,\ servo_packet.tx.elements.args[0],\ servo_packet.tx.elements.args[1],\

servo_packet.tx.elements.args[2],\ servo_packet.tx.elements.args[3],\ servo_packet.tx.elements.args[4],\ servo_packet.tx.elements.args[5],\ servo_packet.tx.elements.args[6],\ servo_packet.tx.elements.args[7],\ servo_packet.tx.elements.args[8],\ servo_packet.tx.elements.args[9],\ servo_packet.tx.elements.args[10],\

servo_packet.tx.elements.args[11],\ servo_packet.tx.elements.args[12],\ servo_packet.tx.elements.args[13],\ servo_packet.tx.elements.args[14],\ servo_packet.tx.elements.args[15],\

Print the set servo ID, acceleration, speed, and position parameters to the PC serial debug assistant.

# 3.2.6 Reading the Servo Status

## 3.2.6.1 Run Program

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

Connect the STM32F103RBT6 microcontroller to the computer and upload the compiled HEX file to the microcontroller.

## 3.2.6.2 Program Outcome

After running the program, the serial debugger prints the sent data packets and the data frames returned by the servo. The operating mode of the servo with the specified ID is set.

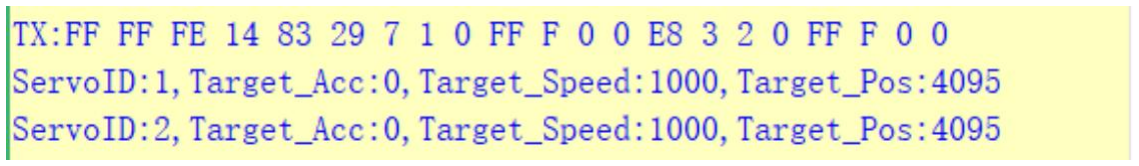
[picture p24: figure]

## 3.2.6.3 Program Brief Analysis

Import the servo communication library and command parsing library.

servo_packet.tx.elements.args[16],\ servo_packet.tx.elements.args[17],\ servo_packet.tx.elements.args[18],\ servo_packet.tx.elements.args[19],\ servo_packet.tx.elements.args[servo_packet.tx.elements.length - 2]\

);
serial_printf_string(info_buf);

sprintf((char*)info_buf,"ServoID:%hu,Target_Acc:%hu,Target_Speed:%hu,Target_Pos:%hu\r\n",\ sync_write1[0][0],sync_write1[0][1],\
sync_write1[0][2],sync_write1[0][3]);
serial_printf_string(info_buf);

sprintf((char
*)info_buf,"ServoID:%hu,Target_Acc:%hu,Target_Speed:%hu,Target_Pos:%hu\r\n",\ sync_write1[1][0],sync_write1[1][1],\
sync_write1[1][2],sync_write1[1][3]);
serial_printf_string(info_buf);

Define the parameters to send and receive.

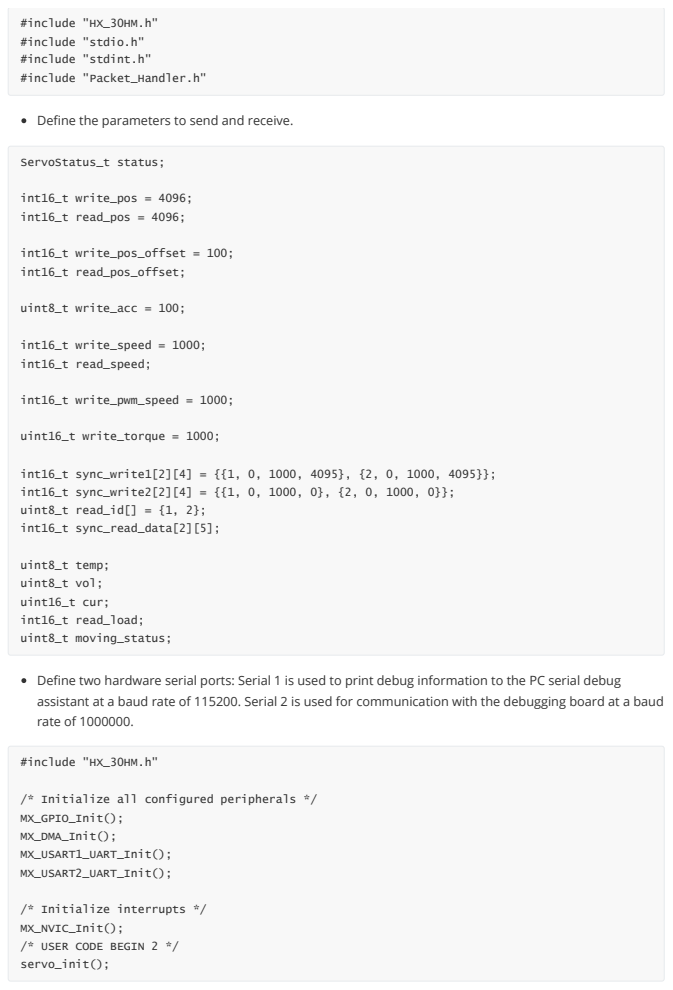
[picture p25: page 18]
#include "HX_30HM.h"; #include "stdio.h"; #include "stdint.h"; #include "Packet_Handler.h"; ServoStatus_t status;; int16_t write_pos = 4096;; int16_t read_pos = 4096;; int16_t write_pos_offset = 100;; int16_t read_pos_offset;; uint8_t write_acc = 100;; int16_t write_speed = 1000;; int16_t read_speed;; int16_t write_pwm_speed = 1000;; uint16_t write_torque = 1000;; int16_t sync_write1[2][4] = {{1, 0, 1000, 4095}, {2, 0, 1000, 4095}};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

The select_mode function sets the operating mode of servo ID 1.

Print the sent data packets and the servo response frames to the PC serial debug assistant.

Print the returned servo ID and operating status parameters to the PC serial debug assistant.

status = servo_select_mode(1, 0);

sprintf((char *)info_buf,"TX:%X %X %X %X %X %X %X %X\r\n",servo_packet.tx.header_1,\ servo_packet.tx.header_2,\
servo_packet.tx.elements.id,\

servo_packet.tx.elements.length,\ servo_packet.tx.elements.cmd,\

servo_packet.tx.elements.args[0],\

servo_packet.tx.elements.args[1],\ servo_packet.tx.elements.args[servo_packet.tx.elements.length - 2]\ );
serial_printf_string(info_buf);

sprintf((char *)info_buf,"RX:%X %X %X %X %X %X\r\n",servo_packet.rx.header_1,\ servo_packet.rx.header_2,\
servo_packet.rx.elements.id,\
servo_packet.rx.elements.length,\
servo_packet.rx.elements.cmd,\ servo_packet.rx.elements.args[servo_packet.rx.elements.length - 2]\

);
serial_printf_string(info_buf);

sprintf((char *)info_buf,"Position:%hu\r\n",read_pos); serial_printf_string(info_buf);

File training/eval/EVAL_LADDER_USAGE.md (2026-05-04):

# Eval Ladder v0.17.0 - Usage Guide

## Overview

The evaluation ladder provides comprehensive post-training benchmarking for standing policies. It runs five standardized difficulty levels that are too expensive to run during training.

**Status**: Patched for robustness (v0.17.2)

## Quick Start

### RECOMMENDED: GPU Evaluation After Training Finishes

**This is the intended and practical way to validate checkpoints.**

```bash
# Stop or pause your training job first to free the GPU

uv run python training/eval/eval_ladder_v0170.py \
  --checkpoint training/checkpoints/ppo_standing_v0171_v00171_20260321_123310-0flajxzh/checkpoint_160_20971520.pkl \
  --config training/configs/ppo_standing_v0171.yaml \
  --platform gpu \
  --suite eval_medium,eval_hard \
  --num-envs 64
```

**Time**: ~5-10 minutes  
**Output**: Critical suites, v0.17.1 target assessment

### Full GPU Evaluation (All Suites)

```bash
uv run python training/eval/eval_ladder_v0170.py \
  --checkpoint training/checkpoints/ppo_standing_v0171_v00171_20260321_123310-0flajxzh/checkpoint_160_20971520.pkl \
  --config training/configs/ppo_standing_v0171.yaml \
  --platform gpu
```

**Time**: ~10-15 minutes  
**Output**: All 5 suites, full ladder assessment

### If GPU Memory Limited (Still Fast)

```bash
uv run python training/eval/eval_ladder_v0170.py \
  --checkpoint training/checkpoints/ppo_standing_v0171_v00171_20260321_123310-0flajxzh/checkpoint_160_20971520.pkl \
  --config training/configs/ppo_standing_v0171.yaml \
  --num-envs 32
```

**Time**: ~10-15 minutes  
**Note**: Still uses GPU (fast), just smaller batch

### CPU Mode (DEBUG/EMERGENCY ONLY)

**⚠️ WARNING: CPU mode is EXTREMELY SLOW and NOT recommended for normal use**

```bash
uv run python training/eval/eval_ladder_v0170.py \
  --checkpoint training/checkpoints/ppo_standing_v0171_v00171_20260321_123310-0flajxzh/checkpoint_160_20971520.pkl \
  --config training/configs/ppo_standing_v0171.yaml \
  --platform cpu \
  --suite eval_hard \
  --num-envs 1
```

**Time**: ~30-60 minutes (for 1 suite, 1 env!)  
**When to use**: Emergency debugging when absolutely no GPU access available  
**Better solutions**: 
1. Stop training to free GPU
2. Use different machine with idle GPU
3. Reduce batch size on GPU (`--num-envs 64`)

## Evaluation Suites

| Suite | Force | Duration | Description | v0.17.1 Target |
|---|---|---|---|---|
| **eval_clean** | 0N | 0 steps | No pushes (baseline) | - |
| **eval_easy** | 5N | 10 steps | Easy regime | **>95%** |
| **eval_medium** | 8N | 10 steps | Boundary regime | **>75%** |
| **eval_hard** | 10N | 10 steps | Hard regime (baseline target) | **>60%** |
| **eval_hard_long** | 9N | 15 steps | Long impulse stress test | - |

## Command-Line Options

### Required Arguments
- `--checkpoint PATH` - Path to checkpoint (.pkl file)
- `--config PATH` - Path to training config (.yaml file)

### Platform Selection
- `--platform {cpu|gpu|auto}` - JAX backend selection (default: auto)
  - `gpu` - **RECOMMENDED**: Force GPU (fast, ~10min for full ladder)
  - `auto` - Let JAX decide (default, usually picks GPU if available)
  - `cpu` - **DEBUG/EMERGENCY ONLY**: Force CPU (extremely slow, ~30-60min for 1 suite)

### Suite Filtering
- `--suite NAMES` - Comma-separated list of suites to run
  - Example: `--suite eval_medium,eval_hard`
  - Valid names: `eval_clean`, `eval_easy`, `eval_medium`, `eval_hard`, `eval_hard_long`
  - Default: all suites

### Evaluation Sizing
- `--num-envs N` - Number of parallel environments (default: 128)
- `--num-steps N` - Episode length (default: 500)
- `--seed N` - Random seed (default: 42)

### Output
- `--output PATH` - Save results to JSON file (optional)

## Output Format

The script prints:
1. **Per-suite results** - Success rate, episode length, failure modes
2. **Summary table** - All suites at a glance
3. **v0.17.1 target assessment** - Which targets are met
4. **Error summary** - Troubleshooting guidance if failures occur

Example output:
```
Running v0.17.0 evaluation ladder:
  Checkpoint: checkpoints/checkpoint_160_20971520.pkl
  Config: configs/ppo_standing_v0171.yaml
  Platform: cpu
  Envs: 128, Steps: 500
  Suites: eval_medium, eval_hard

Running eval_medium...
  Push: 8.0N x 10 steps
  Success: 78.2%
  Ep Length: 482.3
  Height Fail: 12.1%

Running eval_hard...
  Push: 10.0N x 10 steps
  Success: 62.5%
  Ep Length: 465.8
  Height Fail: 24.3%

============================================================
EVALUATION LADDER SUMMARY
============================================================
Suite           Success  Ep Len   Height Fail
------------------------------------------------------------
eval_medium       78.2%   482.3      12.1%
eval_hard         62.5%   465.8      24.3%

============================================================
V0.17.1 TARGET ASSESSMENT
============================================================
✓ eval_medium: 78.2% (target: 75.0%)
✓ eval_hard: 62.5% (target: 60.0%)

✓ ALL v0.17.1 targets met!
```

## Troubleshooting

### GPU Busy / Initialization Fails

**Error**: `cuSolver internal error`, `GPU interconnect information not available`, or CUDA errors

**Root Cause**: Usually the GPU is occupied by a training job, or GPU backend initialization fails

**RECOMMENDED SOLUTIONS** (in order of preference):

1. **Stop or pause training** to free the GPU, then rerun eval on GPU
   ```bash
   # Kill or pause your training job first, then:
   uv run python training/eval/eval_ladder_v0170.py \
     --checkpoint <path> --config <path> --platform gpu
   ```

2. **Use another machine** with idle GPU
   ```bash
   # SSH to different machine with GPU, then run eval
   ```

3. **Reduce batch size** while staying on GPU (still fast)
   ```bash
   uv run python training/eval/eval_ladder_v0170.py \
     --checkpoint <path> --config <path> --platform gpu --num-envs 64
   ```

4. **CPU mode** (LAST RESORT - extremely slow, 30-60min for minimal eval)
   ```bash
   # Only if absolutely no GPU access available
   uv run python training/eval/eval_ladder_v0170.py \
     --checkpoint <path> --config <path> --platform cpu --suite eval_hard --num-envs 1
   ```

### Out of Memory (GPU)

**Error**: CUDA out of memory

**Solution**: Reduce batch size (still uses GPU, still fast)
```bash
uv run python training/eval/eval_ladder_v0170.py \
  --checkpoint <path> --config <path> --num-envs 64
# Or even smaller:
  --num-envs 32
```

### Evaluation Takes Too Long

**Solution 1**: Run critical suites only (fastest)
```bash
uv run python training/eval/eval_ladder_v0170.py \
  --checkpoint <path> --config <path> --suite eval_medium,eval_hard
```

**Solution 2**: Reduce batch size (if using CPU mode)
```bash
uv run python training/eval/eval_ladder_v0170.py \
  --checkpoint <path> --config <path> --num-envs 1
```

## Current v0.17.1 Checkpoint

**Location**:
```
training/checkpoints/ppo_standing_v0171_v00171_20260321_123310-0flajxzh/checkpoint_160_20971520.pkl
```

**Training Run**: `run-20260321_123307-0flajxzh` (iteration 160, 20.97M steps)

**Config**: `training/configs/ppo_standing_v0171.yaml`

**Recommended Command** (GPU, critical suites, practical batch size):
```bash
# Stop training first to free GPU, then:
uv run python training/eval/eval_ladder_v0170.py \
  --checkpoint training/checkpoints/ppo_standing_v0171_v00171_20260321_123310-0flajxzh/checkpoint_160_20971520.pkl \
  --config training/configs/ppo_standing_v0171.yaml \
  --platform gpu \
  --suite eval_medium,eval_hard \
  --num-envs 64
```

**Time**: ~5-10 minutes  
**Why**: Fastest practical way to validate v0.17.1 targets

## Implementation Notes

### Robustness Improvements (v0.17.2)

1. **Platform selection**: `--platform` flag sets `JAX_PLATFORM_NAME` before JAX initialization
2. **Suite filtering**: `--suite` flag allows running specific suites
3. **Error handling**: Continues on suite failures, provides actionable troubleshooting
4. **Target assessment**: Automatically compares results against v0.17.1 targets
5. **Sized fallbacks**: `--num-envs` and `--num-steps` allow debugging with smaller runs

### Why Separate from Training?

Training-time eval runs simplified push/clean passes for efficiency (single JIT compilation). This ladder requires multiple JIT compilations with different push configurations, making it too expensive for training loops. Use this for:
- Final checkpoint selection
- Branch validation
- Performance regression testing

### Checkpoint Compatibility

The ladder loads checkpoints using the same `load_checkpoint()` function as training, ensuring schema compatibility. All v0.17.x standing checkpoints are supported without code changes.

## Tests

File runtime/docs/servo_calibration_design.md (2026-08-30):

# Servo Calibration Design (Runtime)

## Context

WildRobot hardware runtime lives under `runtime/wr_runtime/` and assumes:
- Hiwonder servo position units are in `[0..1000]`
- servo electrical center is `units_center = 500`
- mapping is linear over `[-120°, +120°]` (240° total range)
- runtime commands and reads joints in radians, using a per-joint calibration defined in the runtime JSON config

Calibration is performed with the interactive script:
- `runtime/scripts/calibrate.py`

For a fixture-based, non-moving capture of several joint-zero offsets at once,
use `runtime/scripts/capture_servo_zero.py`.  Like ToddlerBot's zero-point tool,
it relies on the operator installing/aligning the physical calibration reference
before encoder capture.  It cannot infer mechanical zero from encoder data.

```bash
uv run python runtime/scripts/capture_servo_zero.py \
  --config runtime/configs/hardware_config.json \
  --joints leg_pitch \
  --samples 7 \
  --report runtime/calibration/leg_pitch_zero.json \
  --output-config runtime/configs/hardware_config.zero_candidate.json
```

The capture tool never commands servo motion. It requires explicit confirmation
before disabling torque and another confirmation after physical alignment,
redetects the current USB board ports, rejects joints whose raw readings vary by
more than the configured spread, and refuses to overwrite the active hardware
configuration. The candidate config includes the newly detected board paths.

Calibration data is stored directly in the source-of-truth
`runtime/configs/hardware_config.json`; policy bundles do not copy it.

This doc describes the servo calibration model and the operator workflow for per-joint:
1) motor_unit_direction correction
2) center offset in servo units
3) optional joint center angle (`joint_angle_at_servo_center_deg`) used in the rad↔units mapping

For a consolidated reference on coordinate definitions and the end-to-end conversion chain
(`policy_action ∈ [-1, 1]` ↔ `target_rad` ↔ servo units), see `docs/joints_angle.md`.

## Goals

- Calibrate each servo’s **zero/center offset** so that a chosen physical “neutral pose” corresponds to `joint_pos_rad == 0.0` in runtime.
- Calibrate each servo’s **motor sign** so that “positive radians” in runtime matches “positive joint angle” in the MuJoCo model used for training/inference.
- Persist calibration results into the runtime JSON config in a way that is robust, debuggable, and easy to edit by hand.
- Keep the runtime API boundary in radians (do not leak servo units into policy/contract code).

## Non-goals (for initial version)

- Endstop/range calibration (finding actual mechanical min/max).
- Torque/current calibration or PID tuning.
- IMU calibration.
- Automatically inferring MuJoCo “positive direction” physically (we will require human confirmation).

## Terminology

This section is intentionally minimal; the detailed coordinate definitions, sign composition, and
worked examples live in `docs/joints_angle.md`.

- `target_rad`: MuJoCo joint target in radians (runtime commands/readbacks use radians).
- `servo_electrical_unit` (`u_elec`): raw servo position units in `[0..1000]` read/written over the bus.
- `servo_offset_unit`: per-joint integer offset between conceptual units and electrical units:
  - `u = u_elec - servo_offset_unit`
  - conceptual center is `u = 500`
- `joint_angle_at_servo_center_deg`: MuJoCo angle (deg) that corresponds to conceptual `u = 500`.
- `motor_unit_direction ∈ {+1, -1}`: hardware sign correction for the rad↔units mapping.

## Runtime Mapping Model

The runtime uses the mapping implemented in `runtime/wr_runtime/hardware/actuators.py`.

Per joint, calibration values are:
- `motor_unit_direction ∈ {+1, -1}`
- `servo_offset_unit ∈ ℤ`
- `joint_angle_at_servo_center_deg` (optional; default `0`)

## Config Shape

Use `runtime/configs/hardware_config.json` as the canonical in-repo calibration target:
- calibration reads joint names (and servo IDs) from this file
- calibration writes results back to this file (in-place with backups, unless `--output` is provided)

### Config shape (recommended, minimal change)

Under `servo_controller.servos.<joint>`:

```json
{
  "servo_controller": {
    "servos": {
      "left_hip_pitch": { "id": 1, "servo_offset_unit": 0, "motor_unit_direction": 1, "joint_angle_at_servo_center_deg": 0 }
    }
  }
}
```

Where:
- `servo_offset_unit` is an integer in servo units (default: `0`)
- `motor_unit_direction` is `+1` or `-1` (default: `+1`)
- `joint_angle_at_servo_center_deg` is the MuJoCo angle (deg) represented by conceptual servo center `u = 500` (default: `0`); its electrical command is `500 + servo_offset_unit`

Defaults:
- If `motor_unit_direction` is missing, runtime assumes `+1`.
- If `servo_offset_unit` is missing, runtime assumes `0`.
- If `joint_angle_at_servo_center_deg` is missing, runtime assumes `0`.
- The former `joint_angle_at_zero_unit_deg` key is accepted when loading old configs, but serialization writes `joint_angle_at_servo_center_deg`.

### Multiple USB servo boards

Assign each globally unique servo ID to one USB board under
`servo_controller.boards`:

```json
{
  "servo_controller": {
    "type": "hiwonder_ttl_bus",
    "baudrate": 115200,
    "boards": [
      {"name": "left_leg_board", "port": "/dev/serial/by-id/usb-board-left", "servo_ids": [1]},
      {"name": "right_leg_board", "port": "/dev/serial/by-id/usb-board-right", "servo_ids": [5]},
      {"name": "upper_body_board", "port": "/dev/serial/by-id/usb-board-upper", "servo_ids": [40]}
    ],
    "servos": {
      "left_hip_pitch": {"id": 1},
      "right_hip_pitch": {"id": 5},
      "waist_yaw": {"id": 40}
    }
  }
}
```

Do not enter these example assignments manually. With all boards powered and
connected, detect the actual mapping:

```bash
uv run python runtime/scripts/calibrate.py \
  --config runtime/configs/hardware_config.json \
  --calibrate-servo-board
```

The command enumerates USB serial ports using pySerial, probes every ID already
declared under `servo_controller.servos`, and classifies complete buses as
`left_leg_board`, `right_leg_board`, or `upper_body_board` from their joint
names. It writes the mapping only when every ID responds on exactly one board
and each physical bus matches one entire joint group. Missing, duplicate,
mixed-group, or split-leg responses leave the config unchanged. The legacy
`servo_controller.port` format remains valid for a single board.

## Mapping With Offset + Motor Sign + Center

For each joint:
- `motor_unit_direction` from JSON in `{+1, -1}`
- `servo_offset_unit` from JSON (int)

Command (radians → *electrical* units):
```
servo_electrical_unit_cmd = clamp_0_1000(
  units_center
  + servo_offset_unit
  + motor_unit_direction * (target_rad - deg2rad(joint_angle_at_servo_center_deg)) * (1000 / range_rad)
)
```

Readback (electrical units → radians):
```
pos_rad = deg2rad(joint_angle_at_servo_center_deg)
          + motor_unit_direction * ((servo_electrical_unit_read - units_center - servo_offset_unit) * (range_rad / 1000))
```

### Computing `servo_offset_unit` in the presence of `joint_angle_at_servo_center_deg`

If you want a particular reference joint angle `target_ref_rad` to match a measured readback `servo_electrical_unit_read`, rearrange the command equation:

$$
offset\_unit = servo\_electrical\_unit\_read - units\_center - motor\_sign\cdot (target\_ref\_rad - deg2rad(motor\_center\_mujoco\_deg))\cdot (1000 / range\_rad)
$$

Two common special cases:
- If `joint_angle_at_servo_center_deg == 0` and you want `target_ref_rad == 0` at the neutral pose, this reduces to `servo_offset_unit = servo_electrical_unit_read - 500`.
- If you choose `joint_angle_at_servo_center_deg` such that `target_ref_rad == deg2rad(joint_angle_at_servo_center_deg)` for your neutral pose, this reduces to `servo_offset_unit = servo_electrical_unit_read - 500`.

## Calibration UX Overview

Calibration is interactive because:
- The “correct” neutral pose is a physical choice (a human aligns the limb).
- Correct sign requires interpreting the MuJoCo joint’s positive direction, which depends on the model convention.

The script should guide the user joint-by-joint:
0) optionally move the whole robot to a known-safe “home pose” (MuJoCo keyframe)
1) confirm servo ID / comms
2) determine sign (`+1` or `-1`)
3) determine offset at neutral pose
4) write config (with backups)

Important: calibrate `motor_unit_direction` *before* `servo_offset_unit`, because the “motor_unit_direction test” is easier to reason about when the joint is near center.

## Calibration Procedure (per joint)

### Preconditions / safety checklist

- Robot lifted or supported so legs can swing freely.
- Clear access to power switch / e-stop.
- Start with small step sizes (e.g., 2–5 servo units) to avoid slamming into hard stops.
- Set conservative move duration (e.g., 200–500 ms for manual jogging).
- Provide a “panic/unload” key that immediately unloads all servos and exits.

### Optional: go to Home Pose (recommended)

The repo’s sim2real flow recommends using `spec.robot.home_ctrl_rad` as the canonical safe pose (exported from the MuJoCo home keyframe into the policy bundle).

Add a calibrator option to set the robot to that home pose before per-joint calibration:

- CLI: `--go-home` (move all joints once, then proceed)
- CLI: `--bundle <path>` (folder containing `policy_spec.json`)
- CLI: `--scene-xml <path>` (MuJoCo scene XML; e.g. `assets/v2/scene_flat_terrain.xml`)
- CLI: `--keyframes-xml <path>` (direct `keyframes.xml`; e.g. `assets/keyframes.xml`)

Home pose source precedence:
1) If `--bundle` is provided: read `policy_spec.json` and use `spec.robot.home_ctrl_rad` (preferred; does not require MuJoCo installed on the robot).
2) Else if `--scene-xml` is provided and MuJoCo is available: load the scene XML and read the `"home"` keyframe (or keyframe 0) to compute `home_ctrl_rad` in actuator order (matches training/export behavior).
3) Else if `--keyframes-xml` is provided: parse the XML, find `<key name="home" qpos="...">`, and extract the actuated joint slice from `qpos`.
4) Else fallback: `home_ctrl_rad = [0.0] * N` (MuJoCo joint zeros).

#### Reading `home_ctrl_rad` from `keyframes.xml` (no MuJoCo dependency)

This repo includes `assets/keyframes.xml` with a comment that documents the `qpos` layout:
- `[0:3]` root position
- `[3:7]` root quaternion
- `[7:15]` actuated joints (8 DOFs) in radians in the expected joint order

For Stage 1 (8 actuators), the calibrator can:
- split the `qpos` string into floats
- take `qpos[7:7+N]` where `N == len(joint_names_from_config)`
- interpret that as `home_ctrl_rad` in the same joint order as the config

If `N != 8`, do not guess; either require MuJoCo (`--scene-xml`) for name-based extraction or require an explicit mapping.

Execution detail:
- Convert `home_ctrl_rad` (absolute joint targets in radians) to servo commands using the mapping above (using `motor_unit_direction` and `servo_offset_unit`).
- Use a conservative move time (e.g., 500–1000 ms) and allow user confirmation before moving.

### Step A: Select joint

Inputs:
- config path (reads servo IDs, existing offsets/signs)
- list of joints to calibrate (default: config’s joint order / MJCF actuator order)

For each joint, print:
- joint name
- servo ID
- current `sign` and `servo_offset_unit` (legacy `offset_rad` is accepted but interpreted as the same servo-unit value)

### Step B: Determine motor sign

The script should:
1) move the joint near center (safe) using `servo_electrical_unit ≈ 500 + servo_offset_unit` (or defaults)
2) prompt the user to run a motor_unit_direction test:
   - apply a small positive delta (e.g., `+0.1 rad` or `+20 units`)
   - apply a small negative delta
3) ask the user an *explicit physical-direction question*, not “MuJoCo-positive”.

#### Why this matters

“MuJoCo-positive direction” is hard to answer on hardware unless you already know the model’s sign convention for that joint. Humans answer much more reliably when the prompt is phrased as a concrete motion: forward/backward, left/right, toes up/down, etc.

#### Recommended prompt format

For each joint, define a short `positive_motion_hint` string (see the table below), then prompt:

> I will command `+delta`. Did the joint move **toward**: `<positive_motion_hint>`?
>
> - `y` = yes (set `motor_unit_direction = +1`)
> - `n` = no  (set `motor_unit_direction = -1`)
> - `r` = repeat with a different delta

#### Default positive-motion hints (must be verified against the MJCF)

These are suggested human-friendly hints in the robot body frame:
- Body frame assumption for wording: **forward/back** relative to robot facing, **left/right** relative to robot, **up/down** relative to gravity.

| Joint name | `positive_motion_hint` (example wording) |
|---|---|
| `left_hip_pitch` | “left leg swings forward” |
| `right_hip_pitch` | “right leg swings forward” |
| `left_knee_pitch` | “left knee bends (foot moves backward toward the body)” |
| `right_knee_pitch` | “right knee bends (foot moves backward toward the body)” |
| `left_ankle_pitch` | “left toes go up (dorsiflex)” |
| `right_ankle_pitch` | “right toes go up (dorsiflex)” |
| `left_hip_roll` | “left leg moves outward (to the left, away from body midline)” |
| `right_hip_roll` | “right leg moves outward (to the right, away from body midline)” |

Important:
- These hints are only labels for the calibration operator. They **must match the MuJoCo model** you trained against.
- If the MJCF’s sign convention differs, update the hint table (or store per-joint hints in config) so the prompt stays unambiguous.

#### How to verify the hint table against MuJoCo (one-time setup)

- In a MuJoCo viewer (or your existing visualization tooling), apply a small +angle to the joint and observe the motion.
- Record the observed “+angle motion” as the `positive_motion_hint` for that joint.
  - After this, the calibrator can ask a purely physical question and still align to the model’s sign.

Notes:
- The script should display the MuJoCo joint axis direction if available (optional enhancement: parse MJCF and print joint axis vector and joint name), but still rely on a human to interpret it physically.
- If the user is unsure, allow repeating the test with larger/smaller deltas.

### Step C: Determine offset at neutral pose

The script should:
1) choose one explicit reference:
   - `z`: MuJoCo joint zero (`target_ref_rad = 0`), converted through the current servo mapping
   - `r`: start from the servo electrical midpoint (raw unit `500`) and align the joint to `joint_angle_at_servo_center_deg`
2) jog the joint to the user’s chosen “neutral pose” (physical alignment), using keyboard controls:
   - step left/right by configurable `step_units` (e.g., `a`/`d`)
   - optionally bigger steps (`A`/`D`)
3) once the user confirms alignment, read `servo_electrical_unit_read` from the servo
4) compute offset:

```
servo_offset_unit = servo_electrical_unit_read - units_center - motor_unit_direction * (target_ref_rad - deg2rad(joint_angle_at_servo_center_deg)) * (1000 / range_rad)
```

Rationale: we want the chosen reference pose (at `target_ref_rad`) to be consistent with the mapping, so that commanding `target_ref_rad` returns to the same physical alignment.

If you specifically want the neutral pose to correspond to `target_ref_rad == 0`, use `target_ref_rad = 0` in the formula.

### Step D: Persist and verify

Persist:
- update `servo_controller.servos.<joint>.motor_unit_direction` and `servo_controller.servos.<joint>.servo_offset_unit` in the JSON config
- write to disk with:
  - an explicit output path option (recommended), OR
  - in-place update with an automatic timestamped backup

Verify (quick checks):
- command `target_rad = 0.0`, read back `pos_rad` and confirm it is “near 0” (within a small tolerance, e.g., `0.02–0.05 rad`)
- optionally command `±0.2 rad` and confirm motor_unit_direction + magnitude look correct

## File Location and Entrypoints

Preferred (packaged) location:
- `runtime/scripts/calibrate.py` (repo-local tooling; does not require the `wr_runtime` package layout)

Alternative (repo-local tooling, not packaged):
- same as above; run via `uv run python runtime/scripts/calibrate.py ...`

Design preference for now: keep it repo-local and directly depend on `configs` + `wr_runtime.hardware.ttl_servo_controller`.
We can add a console entrypoint later if desired.

## CLI Sketch

Minimal flags:
- `--config <path>`: input hardware config (default: `runtime/configs/hardware_config.json`)
- `--bundle <path>`: optional policy bundle folder (for `policy_spec.json` / `home_ctrl_rad`)
- `--scene-xml <path>`: optional MuJoCo scene XML (read `"home"` keyframe via MuJoCo)
- `--keyframes-xml <path>`: optional keyframes XML (read `"home"` keyframe by parsing `qpos`)
- `--go-home`: optional; move to exported home pose before calibrating
- `--output <path>`: write updated config here (default: in-place with backup)
- `--joints left_hip_pitch,right_knee_pitch` or `--all`
- `--step-units 5`
- `--delta-rad 0.1` (motor_unit_direction test)
- `--move-ms 300` (jog speed)

Non-interactive mode (optional later):
- `--print-only` (compute but do not write)

## Data Ownership and Integration Points

- Calibration is robot-specific: it lives in the hardware config and is applied in the hardware adapter layer.
- Training and `policy_contract` remain in radians; they should not “know” about servo units, offsets, or wiring motor_unit_direction.

## Validation Checklist (post-calibration)

- `wildrobot-run-policy --config <calibrated_config>` starts without interface errors.
- With a simple “hold neutral pose” action (or a small fixed target pose tool), joints move in the expected direction.
- Logged `signals.joint_pos_rad` near the neutral pose are close to zero for all calibrated joints.

## Future Extensions

- Endstop/range calibration: measure usable min/max units per joint; clamp targets accordingly.
- Per-joint neutral pose presets (e.g., a named “stand pose”) to speed up multi-joint alignment.
- Generate a calibration report artifact (JSON + human-readable summary) for versioning and debugging.
- Optional MJCF parsing to show joint axis and expected positive rotation in a more user-friendly way.

## Open Questions

- What is the canonical “neutral pose” definition for each joint (visual description / photos)?
- Do we need a separate calibration history artifact in addition to the canonical `runtime/configs/hardware_config.json`?
- Is servo readback reliable and stable enough to use as the source of truth for offsets, or should we plan for external angle measurement support?

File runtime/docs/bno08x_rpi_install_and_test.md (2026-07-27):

# BNO08X (GY-BNO08X) on Raspberry Pi 4B: Install, Wire, Test, Troubleshoot

This runbook targets the purple `GY-BNO08X` breakout (pins labeled `VCC_3V3`, `GND`, `SCL/SCK/RX`, `SDA/MISO/TX`, `ADDR/MOSI`, `CS`, `INT`, `RST`, `PS0`, `PS1`) wired to a Raspberry Pi 4B over **I2C** or **SPI**.

The WildRobot runtime IMU driver is `runtime/wr_runtime/hardware/bno085.py` (using the Adafruit `adafruit_bno08x` library over I2C or SPI). SPI is the recommended WildRobot runtime wiring after the I2C freshness issues seen during walking tests.

## 1) Wiring (I2C mode)

**Use 3.3V only.** Do not power this IMU from 5V unless your specific board explicitly supports it.

Wire:
- `VCC_3V3` → Pi **3V3** (physical pin 1 or 17)
- `GND` → Pi **GND** (e.g., physical pin 6)
- `SCL/SCK/RX` → Pi **SCL1** (GPIO3, physical pin 5)
- `SDA/MISO/TX` → Pi **SDA1** (GPIO2, physical pin 3)

Optional:
- `INT` → optional (not required by the current runtime driver)
- `RST` → optional (not required by the current runtime driver)

Leave these unconnected for I2C:
- `CS` (SPI chip select)
- SPI pins if you’re not using SPI (`SCK/MOSI/MISO`)

### I2C address selection

The `ADDR/MOSI` pin typically selects the I2C address:
- common addresses: `0x4A` or `0x4B`

You’ll confirm the address with `i2cdetect` (below).

### Interface mode pins (PS0/PS1)

`PS0`/`PS1` select the sensor’s interface at boot (I2C vs UART vs SPI). Many GY-BNO08X boards are pre-strapped for I2C.

For the Adafruit BNO085 breakout pinout, which matches the BNO08x protocol-select behavior:

| `PS1` | `PS0` | Mode |
| --- | --- | --- |
| Low | Low | I2C |
| Low | High | UART-RVC |
| High | Low | UART |
| High | High | SPI |

If `i2cdetect` shows **no device**, the board may be strapped to a non-I2C mode; see Troubleshooting.

### SPI wiring

**Use 3.3V only.** Power down the Pi and IMU before changing the `PS0`/`PS1` straps; those mode-select pins are sampled at sensor boot.

Wire:

| Your Board Label | SPI Alternate Name | Raspberry Pi 4 Pin | Pin Function |
| --- | --- | --- | --- |
| `VCC` / `3V3` / `VIN` | Power | Pin 1 or 17 (3.3V) | 3.3V Power |
| `GND` | Ground | Pin 6, 9, or 14 (GND) | Ground |
| `SCL/SCK/RX` | `SCK` | Pin 23 (GPIO 11) | SPI Clock |
| `SDA/MISO/TX` | `MISO` | Pin 21 (GPIO 9) | Master In Slave Out |
| `ADDR/MOSI` | `MOSI` | Pin 19 (GPIO 10) | Master Out Slave In |
| `CS` | `CS` | Pin 24 (GPIO 8) | Chip Select (CE0) |
| `INT` | `INT` / `IRQ` | Pin 11 (GPIO 17) | Host Interrupt |
| `RST` | Reset | Pin 13 (GPIO 27) | Hardware Reset |
| `PS0` | Protocol Select 0 | Connect to 3.3V | SPI mode select |
| `PS1` | Protocol Select 1 | Connect to 3.3V | SPI mode select |

Board silkscreens vary. Follow the SPI alternate function printed on your board, not just the short I2C label, and confirm against the board schematic before applying power. A swapped `MISO`/`MOSI` wire commonly produces corrupt SPI packet headers during BNO08X reset.

## 2) Enable the Raspberry Pi bus (Ubuntu / Raspberry Pi OS)

### SPI mode

Check that the SPI device exists:

```bash
ls -la /dev/spidev*
```

Expected for the wiring above: `/dev/spidev0.0`.

If it is missing, enable SPI:

```bash
sudo raspi-config
```

Enable: **Interface Options → SPI** then reboot.

On images without `raspi-config`, edit `/boot/firmware/config.txt` (Ubuntu) or `/boot/config.txt` (Pi OS) and ensure:

```ini
dtparam=spi=on
```

Reboot:

```bash
sudo reboot
```

### I2C mode

Check that the I2C device exists:

```bash
ls -la /dev/i2c-*
```

If you do not see `/dev/i2c-1`, enable I2C:

### Option A: `raspi-config` (if available)

```bash
sudo raspi-config
```

Enable: **Interface Options → I2C** then reboot.

### Option B: edit boot config (common on Ubuntu for Pi)

Edit `/boot/firmware/config.txt` (Ubuntu) or `/boot/config.txt` (Pi OS) and ensure:

```ini
dtparam=i2c_arm=on
```

Reboot:

```bash
sudo reboot
```

## 3) Install tools + Python deps

### Optional I2C tools

```bash
sudo apt-get update
sudo apt-get install -y i2c-tools
```

### Runtime Python deps

Install the runtime package on the robot (from repo root):

```bash
cd runtime
pip install -e .
```

The IMU driver imports these at runtime on the Pi:
- `board`
- `busio`
- `adafruit_bno08x`

If those aren’t present, install them (exact method depends on your robot image; common is):

```bash
pip install adafruit-circuitpython-bno08x adafruit-blinka
```

## 4) Detect the sensor on I2C

Run:

```bash
sudo i2cdetect -y 1
```

Expected: you should see a device at `0x4a` or `0x4b`.

Set your runtime JSON accordingly:
- `bno085.i2c_address: "0x4A"` (or `"0x4B"`)

For SPI runtime, set your runtime JSON accordingly:
- `bno085.transport: "spi"`
- `bno085.spi_baudrate: 50000`
- `bno085.spi_read_skip_bytes: 2`
- `bno085.spi_cs_pin: "D8"`
- `bno085.spi_int_pin: "D17"`
- `bno085.spi_reset_pin: "D27"`

The 50 kHz / 2-byte read-skip profile matches the WR Raspberry Pi 4 + BNO08x
breakout measured with `scripts/probe_bno085_spi_raw.py`: SPI mode 3 returns a
valid startup SHTP packet after two leading zero bytes. Adafruit's BNO08x SPI
driver and SparkFun's BNO080 library both use SPI mode 3; this setting only
accounts for the observed leading-byte preamble on this board path.

## 5) Smoke test via the runtime IMU driver

From repo root on the Pi:

```bash
python3 - <<'PY'
import time
import numpy as np
from runtime.wr_runtime.hardware.bno085 import BNO085IMU

imu = BNO085IMU(
    transport="spi",
    spi_baudrate=50000,
    spi_read_skip_bytes=2,
    spi_cs_pin="D8",
    spi_int_pin="D17",
    spi_reset_pin="D27",
    upside_down=False,
    sampling_hz=50,
)
try:
    time.sleep(0.2)
    for i in range(20):
        s = imu.read()
        q = np.asarray(s.quat_wxyz, dtype=np.float32)
        w = float(np.linalg.norm(q))
        g = np.asarray(s.gyro_rad_s, dtype=np.float32)
        print(f\"{i:02d} | quat={q} | |quat|={w:.4f} | gyro(rad/s)={g}\")
        time.sleep(0.05)
finally:
    imu.close()
PY
```

Checks:
- `|quat|` should be ~`1.0` (close to 1, not 0 or NaN).
- When stationary, `gyro(rad/s)` should be near `[0, 0, 0]` (small noise is normal).

If you do not get updates (values stuck), check wiring, power, `PS0`/`PS1`, `/dev/spidev0.0`, and the configured transport.

## 6) Orientation sanity checks (mounting / axis mapping)

The breakout prints an axis diagram. You must ensure the runtime’s IMU frame matches the frame assumptions used in training/runtime:
- `+X` forward
- `+Y` left
- `+Z` up

Practical checks:
- Rotate the robot/yaw to the right around vertical axis: one gyro axis should spike consistently (yaw rate).
- Pitch forward: a different gyro axis should spike.
- Roll right/left: a third axis should spike.

If axes are swapped/negated due to mounting, update the remap in:
- `runtime/wr_runtime/hardware/bno085.py`:
  - `upside_down` handles a simple inverted mount.
  - `axis_map` handles right-handed permutation + sign (e.g., `["+X", "-Y", "-Z"]`) and can be calibrated interactively via
    `runtime/scripts/calibrate.py --calibrate-imu`.

## 7) Troubleshooting

### `i2cdetect` shows nothing

- Confirm 3.3V power and common GND.
- Confirm Pi I2C enabled (`/dev/i2c-1` exists).
- Check wiring: SDA/SCL swapped is common.
- Keep wires short; ensure pull-ups are present (most breakouts include them).
- The board may be strapped to UART/SPI (PS0/PS1). If so, reconfigure straps/jumpers for I2C mode per your board’s schematic.

### `i2cdetect` shows a device, but the Python driver fails

- Confirm the I2C address (`0x4A` vs `0x4B`).
- Ensure `adafruit-blinka` and `adafruit-circuitpython-bno08x` are installed.
- Confirm you’re running on a Pi (the driver imports `board`/`busio`).
- Try lowering bus speed if you suspect signal integrity issues (start with 100kHz).

### SPI debug prints `SHTP READ packet header: ['0xff', '0xff', '0xff', '0xff']`

This means the Pi is reading an all-high/floating MISO line instead of a valid BNO08x SHTP header.

- Confirm `PS1=High` and `PS0=High` before powering the IMU; low/low is I2C mode.
- Confirm `CS` is wired to the configured chip-select pin (`D8` / CE0 / physical pin 24 by default).
- Confirm `SDA/MISO/TX` is wired to Pi MISO (physical pin 21), and `ADDR/MOSI` is wired to Pi MOSI (physical pin 19).
- Confirm `INT` and `RST` are connected; the Adafruit SPI driver requires both for stable SPI operation.
- Confirm common ground and 3.3V power.

### Quaternion looks wrong (norm far from 1, or gravity seems inverted)

- First verify stable power and reliable reads.
- Then verify mounting orientation; set `upside_down` if mounted inverted.
- If still wrong, implement an explicit axis remap (recommended over stacking ad-hoc sign flips).

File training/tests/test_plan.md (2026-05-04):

# WildRobot Test Strategy (v2)

## Executive Summary

This document defines a comprehensive, stage-gated test strategy for the WildRobot project, enabling confident progression from MuJoCo model design through PPO training and ultimately sim-to-real deployment.

This version explicitly introduces **mujoco_robot_config.json as the single runtime source of truth**, generated deterministically from `wildrobot.xml`, and defines mandatory **XML ↔ robot_config consistency contracts**.

---

## Core Principles

1. **Single Source of Truth at Runtime**
   - All product code and test code MUST consume `mujoco_robot_config.json`
   - Direct parsing of `wildrobot.xml` is only allowed inside the generator and its tests

2. **Authoritative Authoring Artifact**
   - `wildrobot.xml` is the authoritative model definition
   - Any semantic change to the robot must flow through regeneration of `mujoco_robot_config.json`

3. **Fail Fast on Structural Drift**
   - XML/config inconsistencies are treated as hard errors
   - No training or reward tests run if the contract fails

## Non-negotiables

### 1) No hard-coded indices
Never hard-code qpos or qvel slices, geom IDs, site IDs, or actuator indices in reward, observations, features, or tests.

Instead:
- derive indices from the MuJoCo model once,
- store them in a **schema contract artifact**,
- assert contract stability in CI,
- use the contract everywhere (env, reward, MJX parity).

### 2) Determinism and reproducibility
Every training and validation run must record:
- git commit hash
- config hash
- model hash (xml and referenced assets)
- random seed
- MuJoCo version
- JAX and XLA versions
- device type

### 3) Tests are stage-gated
A test is not "nice to have." It is a gate for moving to the next stage:
- Stage 1: PPO task learning
- Stage 2: sim-to-real

---

## Scope and artifacts under test

**Inputs**
- `assets/v1/wildrobot.xml` (MuJoCo model), referenced meshes and materials
- environment scene XML (e.g. `assets/v1/scene_flat_terrain.xml`)
- training config (`training/configs/ppo_walking_v0201_smoke.yaml`)
- training and rollout code (`training/*`)

**Outputs**
- schema contract JSON
- trained checkpoints
- evaluation rollouts and metrics
- reference dataset segments (Stage 2)
- sim-to-real calibration pack (mass, friction, actuator limits, sensor noise)

---

## Test tiers and CI schedule

| Tier | When | Runtime | Purpose |
|---|---:|---:|---|
| T0: Pre-commit | local | < 2 min | fast unit and schema checks |
| T1: PR gate | CI | 10-20 min | simulation correctness and small training smoke |
| T2: Nightly | CI | 1-3 hours | MJX parity, longer training, robustness sweeps |
| T3: Release | manual | half day | sim-to-real readiness pack and hardware checklist |

Recommended pytest markers:
- `@pytest.mark.unit` (T0)
- `@pytest.mark.sim` (T1)
- `@pytest.mark.train` (T1/T2)
- `@pytest.mark.mjx` (T2)
- `@pytest.mark.robust` (T2/T3)
- `@pytest.mark.s2r` (T3)

---

## Layer 0: Schema Contract (Foundation)

### Objective
Guarantee consistency between `wildrobot.xml` and `mujoco_robot_config.json` and enforce config-only runtime access.

### 0.1 Generation and Snapshot Tests

**Test 0.1.1: Deterministic Generation**
```python
def test_deterministic_generation(self):
    """
    Purpose: Verify schema generation is deterministic.

    Procedure:
    1. Generate mujoco_robot_config.json twice from the same XML
    2. Compare outputs

    Assertions:
    - Byte-identical or semantically identical output
    """
    config1 = generate_robot_config("assets/v1/wildrobot.xml")
    config2 = generate_robot_config("assets/v1/wildrobot.xml")
    assert config1 == config2, "Generation not deterministic"
```

**Test 0.1.2: Snapshot Consistency**
```python
def test_snapshot_consistency(self):
    """
    Purpose: Detect unintentional XML changes.

    Procedure:
    1. Regenerate config from current XML
    2. Diff against committed mujoco_robot_config.json

    Assertions:
    - Any difference fails with actionable diff message
    """
    regenerated = generate_robot_config("assets/v1/wildrobot.xml")
    committed = load_yaml("assets/v1/mujoco_robot_config.json")
    assert regenerated == committed, (
        "Schema mismatch! XML has changed. "
        "Run `python scripts/generate_config.py` if intentional."
    )
```

**Test 0.1.3: Provenance Validation**
```python
def test_provenance_fields(self, robot_config):
    """
    Purpose: Ensure config contains provenance metadata.

    Assertions:
    - source_xml_sha256 exists and is 64 hex chars
    - generator_version exists
    - schema_version exists
    """
    assert "source_xml_sha256" in robot_config
    assert len(robot_config["source_xml_sha256"]) == 64
    assert "generator_version" in robot_config
    assert "schema_version" in robot_config
```

### 0.2 Contract Content (Minimum Required)

Derived from MuJoCo `MjModel` created from `assets/v1/wildrobot.xml`:

#### 0.2.1 Joints (Real Joints Only)

| Field | Description |
|---|---|
| `name` | Joint name (excluding `_mimic`) |
| `type` | Joint type (hinge, ball, etc.) |
| `qpos_adr` | Address in qpos array |
| `dof_adr` | Address in qvel/dof array |
| `range` | Joint limits [min, max] |
| `limited` | Whether limits are enforced |
| `body_name` | Parent body name |

**Test 0.2.1: No Mimic Joints in Schema**
```python
def test_no_mimic_joints_in_schema(self, robot_schema):
    """
    Purpose: Verify _mimic joints are excluded.

    Assertions:
    - No joint name contains "_mimic"
    """
    for joint in robot_schema["joints"]:
        assert "_mimic" not in joint["name"], f"Mimic joint leaked: {joint['name']}"
```

#### 0.2.2 Actuators

| Field | Description |
|---|---|
| `name` | Actuator name |
| `joint_name` | Target joint name |
| `dof_adr` | DOF address |
| `gear` | Gear ratio |
| `ctrlrange` | Control limits [min, max] |
| `forcerange` | Force limits (if applicable) |

**Test 0.2.2: Actuators Target Valid Joints**
```python
def test_actuator_targets_valid_joints(self, robot_schema):
    """
    Purpose: Verify no actuator targets a _mimic joint.

    Assertions:
    - All actuator target joints exist in schema joints
    - No actuator targets a _mimic joint
    """
    joint_names = {j["name"] for j in robot_schema["joints"]}
    for actuator in robot_schema["actuators"]:
        assert "_mimic" not in actuator["joint_name"]
        assert actuator["joint_name"] in joint_names
```

#### 0.2.3 Foot Contact Sets

Two disjoint sets of geom IDs:
- Left foot: `left_toe`, `left_heel`
- Right foot: `right_toe`, `right_heel`

**Test 0.2.3: Foot Geoms Are Valid**
```python
def test_foot_geoms_valid(self, robot_schema):
    """
    Purpose: Verify foot geoms are correctly identified.

    Assertions:
    - Left and right foot geom sets are disjoint
    - All foot geoms are collision-enabled
    - No foot geom belongs to a _mimic body
    """
    left_ids = {g["id"] for g in robot_schema["left_foot_geoms"]}
    right_ids = {g["id"] for g in robot_schema["right_foot_geoms"]}

    assert left_ids.isdisjoint(right_ids), "Foot geom sets overlap!"

    for geom in robot_schema["left_foot_geoms"] + robot_schema["right_foot_geoms"]:
        assert "_mimic" not in geom["body"], f"Mimic geom leaked: {geom}"
        assert geom["contype"] > 0 or geom["conaffinity"] > 0, f"Geom not collision-enabled: {geom}"
```

#### 0.2.4 Base Definition

| Field | Description |
|---|---|
| `body_name` | Base body name |
| `freejoint_name` | Free joint name (if used) |
| `qpos_adr` | qpos slice for pos + quat (7 values) |
| `dof_adr` | qvel slice for linvel + angvel (6 values) |

---

## Layer 1: Config and Runtime Contracts

### 1.1 Training Config Schema Validation

**Test 1.1.1: Required Keys Exist**
```python
def test_training_config_required_keys(self, training_config):
    """
    Purpose: Verify all required config sections exist.

    Assertions:
    - Required keys: env, ppo, networks, reward_weights, checkpoints, logging
    """
    required = ["env", "ppo", "networks", "reward_weights", "checkpoints", "logging"]
    for key in required:
        assert key in training_config, f"Missing required key: {key}"
```

**Test 1.1.2: Timestep Consistency**
```python
def test_timestep_consistency(self, training_config):
    """
    Purpose: Verify timestep configuration is valid.

    Assertions:
    - sim_dt < ctrl_dt
    - ctrl_dt / sim_dt is integer
    - ctrl_dt = 0.02, sim_dt = 0.002 → ratio = 10
    """
    sim_dt = training_config.env.sim_dt
    ctrl_dt = training_config.env.ctrl_dt

    assert sim_dt < ctrl_dt, f"sim_dt ({sim_dt}) must be < ctrl_dt ({ctrl_dt})"
    ratio = ctrl_dt / sim_dt
    assert ratio == int(ratio), f"ctrl_dt/sim_dt must be integer, got {ratio}"
```

**Test 1.1.3: Reward Weights Valid**
```python
def test_reward_weights_valid(self, training_config):
    """
    Purpose: Verify reward weights are valid numbers.

    Assertions:
    - All weights are finite (not NaN or Inf)
    - All weights are non-negative
    """
    for name, weight in training_config.reward_weights.items():
        assert np.isfinite(weight), f"Reward weight {name} is not finite: {weight}"
        assert weight >= 0, f"Reward weight {name} is negative: {weight}"
```

### 1.2 Static Consistency Checks

**Test 1.2.1: Action Dim Matches Actuators**
```python
def test_action_dim_matches_actuators(self, training_config, robot_schema):
    """
    Purpose: Verify action dimension matches robot actuator count.

    Assertions:
    - training_config.action_dim == len(robot_schema.actuators)
    """
    assert training_config.env.action_dim == len(robot_schema["actuators"]), (
        f"Action dim mismatch: config={training_config.env.action_dim}, "
        f"actuators={len(robot_schema['actuators'])}"
    )
```

---

## Layer 2: MuJoCo Model Validation (Authoring Quality)

These tests run on the raw MuJoCo model without RL.

### 2.1 Load and Step Smoke

**Test 2.1.1: Model Loads and Steps Without Explosion**
```python
def test_model_stability(self, mj_model, mj_data):
    """
    Purpose: Verify model is stable under simulation.

    Procedure:
    1. Load scene_flat_terrain.xml
    2. Run 1000 sim steps with zero controls

    Assertions:
    - No NaN in qpos or qvel
    - No constraint solver warnings above threshold
    - Energy does not explode (< 1e6 J)
    """
    import mujoco

    for _ in range(1000):
        mj_data.ctrl[:] = 0
        mujoco.mj_step(mj_model, mj_data)

        assert not np.any(np.isnan(mj_data.qpos)), "NaN in qpos"
        assert not np.any(np.isnan(mj_data.qvel)), "NaN in qvel"

    # Check energy didn't explode
    kinetic = 0.5 * np.sum(mj_data.qvel ** 2)
    assert kinetic < 1e6, f"Energy exploded: {kinetic}"
```

### 2.2 Kinematic Sanity

**Test 2.2.1: Initial Pose Valid**
```python
def test_initial_pose_valid(self, mj_model, mj_data, training_config):
    """
    Purpose: Verify reset pose is physically valid.

    Assertions:
    - Base height in [min_height, max_height]
    - Base pitch and roll < 0.1 rad
    - All joints within limits
    - No initial penetrations
    """
    import mujoco

    mujoco.mj_resetData(mj_model, mj_data)
    mujoco.mj_forward(mj_model, mj_data)

    # Base height
    base_height = mj_data.qpos[2]
    assert training_config.env.min_height <= base_height <= training_config.env.max_height

    # Base orientation (pitch, roll near zero)
    quat = mj_data.qpos[3:7]
    # Convert to euler and check
    # ... (implementation depends on your math utilities)

    # Joint limits
    for i in range(mj_model.njnt):
        if mj_model.jnt_limited[i]:
            qpos_adr = mj_model.jnt_qposadr[i]
            pos = mj_data.qpos[qpos_adr]
            low, high = mj_model.jnt_range[i]
            assert low <= pos <= high, f"Joint {i} out of limits: {pos} not in [{low}, {high}]"
```
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

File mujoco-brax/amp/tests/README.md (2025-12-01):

# WildRobot AMP Test Suite

**Purpose:** Catch JAX pytree structure errors and other contract violations **before** starting expensive training runs.

---

## 🎯 **Why These Tests Are Critical**

### **The Problem:**
JAX's `jax.lax.scan` requires that the state structure (pytree) remains **identical** between iterations:
- `reset()` must initialize **all** fields that `step()` will use
- Missing even a single field causes: `TypeError: scan body function carry input and carry output must have the same pytree structure`

### **The Cost:**
- Training takes **8-10 hours** per run
- Finding a structure error **after starting** wastes GPU time
- **Solution:** Run these tests (takes ~30 seconds) before every training run

---

## 🧪 **Test Categories**
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

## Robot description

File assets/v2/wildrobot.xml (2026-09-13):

<mujoco model="WildRobot">
  <option>
    <flag eulerdamp="disable" />
  </option>
  <compiler angle="radian" meshdir="assets" autolimits="true" />
  <default>
    <default class="WildRobot">
      <joint frictionloss="0.1" armature="0.005" />
      <position kp="50" dampratio="1" />
      <default class="visual">
        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
      </default>
      <default class="collision">
        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
      </default>
    </default>
    <default class="htd45hServo">
      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
      <joint damping="1.10618" frictionloss="0.324094" armature="0.024992" />
      <position kp="31.902" kv="0.5" forcerange="-4.0 4.0" />
    </default>
    <default class="backlash">
      <joint damping="0.01" frictionloss="0" armature="0.01" limited="true" range="-0.008726646259971648 0.008726646259971648" />
    </default>
  </default>
  <worldbody>
    <body name="waist" pos="0 0 0.48" quat="1 0 0 0" childclass="WildRobot">
      <freejoint name="waist_freejoint" />
      <inertial pos="-0.00192043 -3.154e-05 0.00674673" mass="0.430469" fullinertia="0.00094036 0.00068072 0.000658714 -7.0859e-08 1.28322e-05 5.13544e-07" />
      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
      <body name="left_hip" pos="-4.74705e-05 0.0536 -0.0335836" quat="0.000292354 -0.000292013 0.707519 -0.706694">
        <joint axis="0 0 1" name="left_hip_pitch" type="hinge" range="-0.5235987755982988 1.5707963267948966" class="htd45hServo" />
        <inertial pos="-0.00308194 -0.010076 -0.0341664" mass="0.0777257" fullinertia="1.51479e-05 1.49785e-05 2.29883e-05 5.9627e-07 -3.46054e-07 2.9477e-08" />
        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
        <body name="left_upper_leg" pos="-0.0268 -0.000416429 -0.0356475" quat="0.707399 -0.000412109 0.706814 0.00041245">
          <joint axis="0 0 1" name="left_hip_roll" type="hinge" range="-1.5707963267948983 0.17453292519943117" class="htd45hServo" />
          <inertial pos="-0.000655711 0.156941 0.0267017" mass="0.225743" fullinertia="0.000951884 0.000120859 0.000943024 6.08104e-06 -4.455e-09 1.07277e-06" />
          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
          <body name="left_lower_leg" pos="-0.0390396 0.192552 0.0267" quat="0 -0.707107 0 -0.707107">
            <joint axis="0 0 1" name="left_knee_pitch" type="hinge" range="0.0 2.0943951023931953" class="htd45hServo" />
            <inertial pos="-0.000562096 -0.109045 0.0383335" mass="0.353081" fullinertia="0.00144776 0.000641316 0.00138436 2.04089e-05 1.35312e-07 -1.60008e-05" />
            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
            <body name="left_servo_bracket_top" pos="-4.74705e-05 -0.179984 0.0122396" quat="2.40923e-07 -0.00041321 0.000583051 -1">
              <joint axis="0 0 1" name="left_ankle_pitch" type="hinge" range="-0.6981317007977318 0.7853981633974483" class="htd45hServo" />
              <inertial pos="0.000191186 0.0196763 0.0256081" mass="0.0228008" fullinertia="1.05321e-05 7.76967e-06 4.83835e-06 -5.5465e-08 -5.195e-09 -2.86672e-07" />
              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
              <body name="left_foot" pos="0.0114 0.0324 0.0268" quat="0.5 -0.5 -0.5 0.5">
                <joint axis="0 0 1" name="left_ankle_roll" type="hinge" range="-0.7853981633973959 0.7853981633975007" class="htd45hServo" />
                <inertial pos="0.0194708 0.00157184 -0.00951404" mass="0.319393" fullinertia="0.000844392 0.000734507 0.000188519 1.23162e-05 -2.01583e-05 9.89625e-06" />
                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
              </body>
            </body>
          </body>
        </body>
      </body>
      <body name="right_hip" pos="4.74705e-05 -0.0536 -0.0335836" quat="0.706694 -0.707519 -0.000292013 0.000292354">
        <joint axis="0 0 1" name="right_hip_pitch" type="hinge" range="-1.5707963267948966 0.5235987755982988" class="htd45hServo" />
        <inertial pos="0.00308194 -0.010076 -0.0342047" mass="0.0777257" fullinertia="1.51563e-05 1.49869e-05 2.29883e-05 -5.9627e-07 3.31597e-07 2.6146e-08" />
        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
        <body name="right_upper_leg" pos="0.0268 -0.000416429 -0.0355525" quat="0.706814 -0.00041245 -0.707399 -0.000412109">
          <joint axis="0 0 1" name="right_hip_roll" type="hinge" range="-0.1745329251994365 1.570796326794893" class="htd45hServo" />
          <inertial pos="-0.00114521 0.156941 0.0267021" mass="0.225743" fullinertia="0.000951884 0.000121335 0.0009435 1.10498e-05 -1.014e-08 1.06866e-06" />
          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
          <body name="right_lower_leg" pos="-0.0390396 0.192552 0.0267" quat="0 -0.707107 -0 -0.707107">
            <joint axis="0 0 1" name="right_knee_pitch" type="hinge" range="0.0 2.0943951023931953" class="htd45hServo" />
            <inertial pos="-0.000562096 -0.109045 0.0383335" mass="0.353081" fullinertia="0.00144776 0.000641316 0.00138436 2.04089e-05 1.35312e-07 -1.60008e-05" />
            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
            <body name="right_servo_bracket_top" pos="-4.74705e-05 -0.179984 0.0122396" quat="2.40923e-07 -0.00041321 0.000583051 -1">
              <joint axis="0 0 1" name="right_ankle_pitch" type="hinge" range="-0.6981317007977274 0.7853981633974527" class="htd45hServo" />
              <inertial pos="0.000191186 0.0196763 0.0256081" mass="0.0228008" fullinertia="1.05321e-05 7.76967e-06 4.83835e-06 -5.5465e-08 -5.195e-09 -2.86672e-07" />
              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
              <body name="right_foot" pos="0.0114 0.0324 0.0268" quat="0.5 0.5 -0.5 -0.5">
                <joint axis="0 0 1" name="right_ankle_roll" type="hinge" range="-0.7853981633974465 0.78539816339745" class="htd45hServo" />
                <inertial pos="-0.0195502 0.00180079 -0.00954602" mass="0.319393" fullinertia="0.000844038 0.000734364 0.000188155 -1.21026e-05 2.11759e-05 9.35734e-06" />
                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
              </body>
            </body>
          </body>
        </body>
      </body>
      <body name="upperbody" pos="1.97751e-05 4.17458e-05 0.0482" quat="0.000704463 0.707107 0.707106 0.000120096">
        <joint axis="0 0 1" name="waist_yaw" type="hinge" range="-0.5235987755982979 0.5235987755982997" class="htd45hServo" />
        <inertial pos="-0.00157757 0.00911822 -0.0973338" mass="0.499264" fullinertia="0.00147301 0.00220317 0.00108085 1.64526e-05 -4.14031e-06 -4.24312e-05" />
        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
        <body name="right_shoulder" pos="-0.0816463 -0.000258254 -0.13948" quat="0.500498 0.499915 0.499502 0.500085">
          <joint axis="0 0 1" name="right_shoulder_pitch" type="hinge" range="-3.141592653589793 0.5235987755982988" class="htd45hServo" />
          <inertial pos="0.000526331 -1.35081e-05 -0.0353293" mass="0.111961" fullinertia="4.43825e-05 4.32148e-05 2.84434e-05 -7.145e-09 8.4443e-08 4.452e-09" />
          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
          <body name="right_upper_arm" pos="0.0241871 4.69936e-05 -0.0433792" quat="0.501246 -0.498337 -0.498751 0.501658">
            <joint axis="0 0 1" name="right_shoulder_roll" type="hinge" range="-0.5235987755982991 2.96705972839036" class="htd45hServo" />
            <inertial pos="0.0739851 0.0130007 0.0246353" mass="0.0589168" fullinertia="2.55708e-05 0.000149279 0.000153315 -2.23053e-05 -2.70428e-06 -4.75304e-07" />
            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
            <body name="right_fore_arm" pos="0.143931 0.0498494 0.0253003" quat="0.541676 -0.454519 -0.541669 -0.454525">
              <joint axis="0 0 1" name="right_elbow_pitch" type="hinge" range="0.0 1.5707963267948966" class="htd45hServo" />
              <inertial pos="0.00185718 0.104961 -0.0250906" mass="0.384095" fullinertia="0.00181645 0.000222339 0.00186965 1.0405e-05 4.02153e-06 -2.97495e-06" />
              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
            </body>
          </body>
        </body>
        <body name="left_shoulder" pos="0.0811537 -0.000341746 -0.13948" quat="0.500085 0.499502 -0.499915 -0.500498">
          <joint axis="0 0 1" name="left_shoulder_pitch" type="hinge" range="-0.5235987755982988 3.141592653589793" class="htd45hServo" />
          <inertial pos="-0.000526331 1.35081e-05 -0.0353293" mass="0.111961" fullinertia="4.43825e-05 4.32148e-05 2.84434e-05 -7.145e-09 -8.4443e-08 -4.452e-09" />
          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
          <body name="left_upper_arm" pos="-0.0241871 -4.69936e-05 -0.0433792" quat="0.501658 -0.498751 0.498337 -0.501246">
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

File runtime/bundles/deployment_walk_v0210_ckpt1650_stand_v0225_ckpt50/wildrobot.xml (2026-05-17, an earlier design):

<mujoco model="WildRobot">
  <option>
    <flag eulerdamp="disable" />
  </option>
  <compiler angle="radian" meshdir="assets" autolimits="true" />
  <default>
    <default class="WildRobot">
      <joint frictionloss="0.1" armature="0.005" />
      <position kp="50" dampratio="1" />
      <default class="visual">
        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
      </default>
      <default class="collision">
        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
      </default>
    </default>
    <default class="htd45hServo">
      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
      <joint damping="0.08516" frictionloss="0.022275" armature="0.024992" />
      <position kp="21.1" kv="0.5" forcerange="-4.0 4.0" />
    </default>
    <default class="backlash">
      <joint damping="0.01" frictionloss="0" armature="0.01" limited="true" range="-0.008726646259971648 0.008726646259971648" />
    </default>
  </default>
  <worldbody>
    <body name="waist" pos="0 0 0.48" quat="1 0 0 0" childclass="WildRobot">
      <freejoint name="waist_freejoint" />
      <inertial pos="-0.00188474 -3.09539e-05 0.0059955" mass="0.438621" fullinertia="0.000998015 0.000697543 0.000702081 -7.1344e-08 1.34532e-05 5.23744e-07" />
      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
      <body name="left_hip" pos="-4.74705e-05 0.0536 -0.0335836" quat="0.000292354 -0.000292013 0.707519 -0.706694">
        <joint axis="0 0 1" name="left_hip_pitch" type="hinge" range="-0.5235987755978769 1.5707963267953184" class="htd45hServo" />
        <inertial pos="-0.00281909 -0.00921669 -0.0330577" mass="0.0849728" fullinertia="2.00312e-05 1.92517e-05 2.44439e-05 3.90415e-07 -8.15259e-07 -1.50454e-06" />
        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
        <body name="left_upper_leg" pos="-0.0268 -0.000416429 -0.0364975" quat="0.707399 -0.000412109 0.706814 0.00041245">
          <joint axis="0 0 1" name="left_hip_roll" type="hinge" range="-1.5707963267949 0.1745329251994294" class="htd45hServo" />
          <inertial pos="-0.0012104 0.157633 0.0266968" mass="0.230252" fullinertia="0.000959734 0.000124736 0.000952616 1.17627e-05 -9.658e-09 1.0912e-06" />
          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
          <body name="left_lower_leg" pos="-0.0272 0.192552 0.0267" quat="0 0.707107 -0 0.707107">
            <joint axis="0 0 1" name="left_knee_pitch" type="hinge" range="0.0 2.0943951023931953" class="htd45hServo" />
            <inertial pos="-0.000528557 -0.102714 0.0267452" mass="0.375475" fullinertia="0.00172108 0.00066678 0.0016354 1.9152e-05 9.3642e-08 -2.40247e-05" />
            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
            <body name="left_servo_bracket_top" pos="-4.74705e-05 -0.179984 0.000442075" quat="2.40923e-07 -0.00041321 0.000583051 -1">
              <joint axis="0 0 1" name="left_ankle_pitch" type="hinge" range="-0.6981317007977318 0.7853981633974483" class="htd45hServo" />
              <inertial pos="0.000665032 0.0193435 0.025829" mass="0.0166724" fullinertia="7.41725e-06 5.45754e-06 3.50571e-06 -1.33679e-07 -1.0767e-08 -1.41116e-07" />
              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
              <body name="left_foot" pos="0.0114 0.0314 0.0268" quat="0.5 -0.5 -0.5 0.5">
                <joint axis="0 0 1" name="left_ankle_roll" type="hinge" range="-0.7853981633974003 0.7853981633974962" class="htd45hServo" />
                <inertial pos="0.0194695 0.00155656 -0.00951744" mass="0.319241" fullinertia="0.000843554 0.000733825 0.000188361 1.23293e-05 -2.01555e-05 9.93031e-06" />
                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
              </body>
            </body>
          </body>
        </body>
      </body>
      <body name="right_hip" pos="4.74705e-05 -0.0536 -0.0335836" quat="0.706694 -0.707519 -0.000292013 0.000292354">
        <joint axis="0 0 1" name="right_hip_pitch" type="hinge" range="-1.5707963267948957 0.5235987755982997" class="htd45hServo" />
        <inertial pos="0.00281909 -0.00921669 -0.0330927" mass="0.0849728" fullinertia="2.00512e-05 1.92718e-05 2.44439e-05 -3.90415e-07 8.01584e-07 -1.51042e-06" />
        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
        <body name="right_upper_leg" pos="0.0268 -0.000416429 -0.0364025" quat="0.706814 -0.00041245 -0.707399 -0.000412109">
          <joint axis="0 0 1" name="right_hip_roll" type="hinge" range="-0.1745329251994374 1.5707963267948921" class="htd45hServo" />
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

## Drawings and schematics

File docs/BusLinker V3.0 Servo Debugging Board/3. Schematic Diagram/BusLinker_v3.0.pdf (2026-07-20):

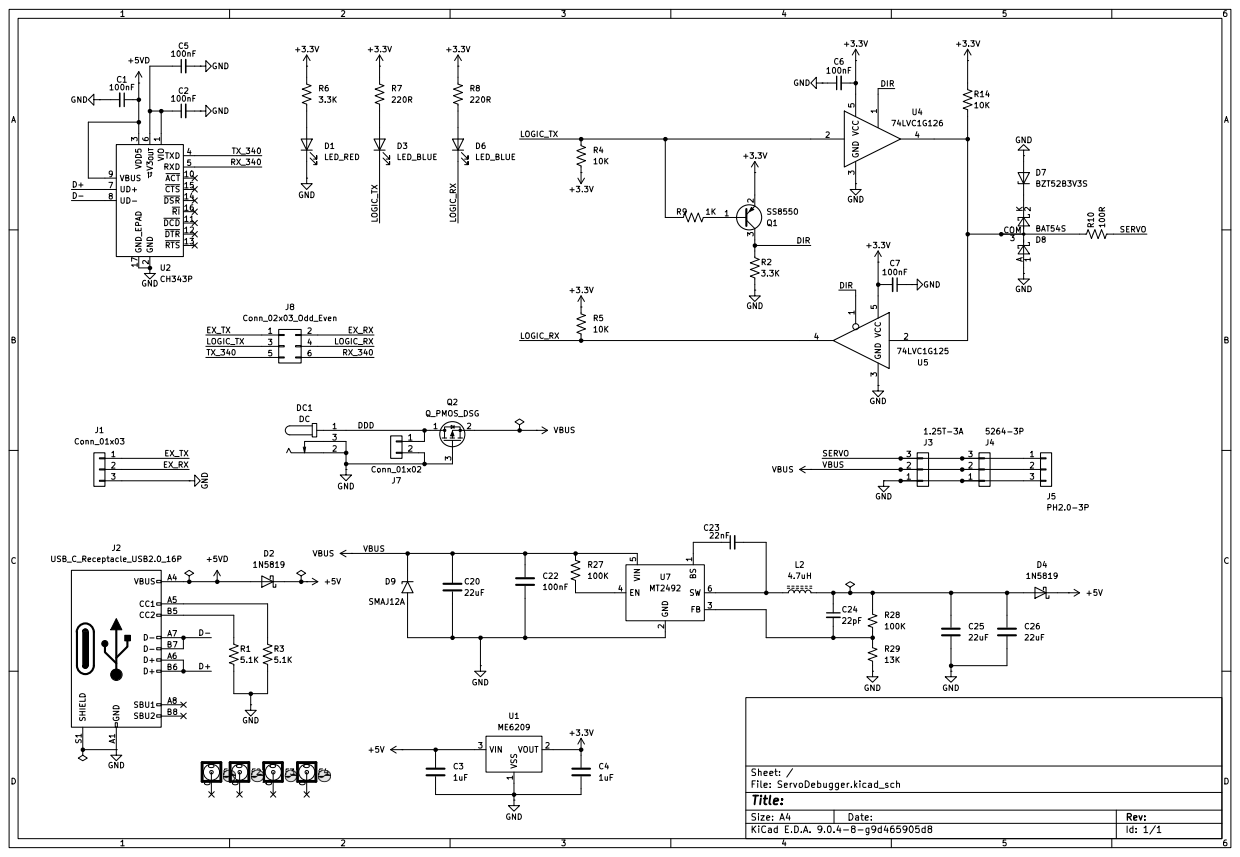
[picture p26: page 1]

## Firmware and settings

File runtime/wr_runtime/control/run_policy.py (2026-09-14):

"""``wildrobot-run-policy`` — deterministic control loop for the latest bundle.

Loads a deployment bundle containing standing and walking policy contracts and
uses the repository's canonical hardware configuration. Supports a hardware-free
``--dry-run`` mode for smoke tests and safe validation on a developer machine.

Examples
--------
Dry run (no hardware), 5 steps, straight walk::

    uv run --project runtime wildrobot-run-policy \
      --bundle /tmp/wr_runtime_smoke9_bundle_check \
      --dry-run --max-steps 5 --velocity-cmd 0.13,0.0,0.0

Hardware run (on the robot), forward walk for 500 control steps::

    uv run --project runtime wildrobot-run-policy \
      --bundle /path/to/bundle \
      --max-steps 500 --velocity-cmd 0.13,0.0,0.0

Stable-only run with the integrated standing stabilizer::

    uv run --project runtime wildrobot-run-policy \
      --bundle /path/to/bundle \
      --stable-only
"""

from __future__ import annotations

import argparse
import contextlib
import datetime as dt
import faulthandler
import itertools
import json
import math
import re
import signal
import sys
import time
import traceback
from collections import deque
from pathlib import Path
from types import SimpleNamespace
from typing import Any, Callable, List, Optional, Sequence, TextIO

import numpy as np

from policy_contract.calib import NumpyCalibOps
from policy_contract.spec import PolicyBundle, validate_spec

from wr_runtime.inference.onnx_policy import OnnxPolicy
from wr_runtime.control.mock_robot_io import MockRobotIO
from wr_runtime.control.policy_runner import RuntimePolicyRunner
from wr_runtime.control.runtime_policy_config import RuntimePolicyConfig
from wr_runtime.control.runtime_policy_config import StandingRuntimePolicyConfig
from wr_runtime.control.standing_policy_runner import StandingPolicyRunner
from wr_runtime.deployment_bundle import DeploymentBundle, is_deployment_bundle
from wr_runtime.logging.policy_telemetry import PolicyTelemetryRecorder


_LEG_LOG_JOINTS = (
    ("LHP", "left_hip_pitch"),
    ("LHR", "left_hip_roll"),
    ("LK", "left_knee_pitch"),
    ("LAP", "left_ankle_pitch"),
    ("LAR", "left_ankle_roll"),
    ("RHP", "right_hip_pitch"),
    ("RHR", "right_hip_roll"),
    ("RK", "right_knee_pitch"),
    ("RAP", "right_ankle_pitch"),
    ("RAR", "right_ankle_roll"),
)

_FOOT_SWITCH_LABELS = ("left_toe", "left_heel", "right_toe", "right_heel")
_ANSI_YELLOW = "\033[33m"
_ANSI_RESET = "\033[0m"
_STARTUP_STABILITY_WINDOW_S = 0.4
_STARTUP_STABILITY_MIN_FOOTSWITCH_PRESSED_RATIO = 0.9
_STARTUP_STABILITY_MAX_TILT_DEG = 15.0
_STARTUP_STABILITY_MAX_GYRO_RAD_S = 0.35
_STARTUP_STABILITY_MAX_LEG_ERROR_DEG = 8.0
_STARTUP_POSE_BLEND_S = 2.0
_STARTUP_POSE_BLEND_MAX_S = 3.0
_STARTUP_POSE_BLEND_RATE_DEG_S = 15.0
_STARTUP_POSE_HOLD_S = 5.0
_STARTUP_POSE_HARD_MAX_TILT_DEG = 45.0
_STARTUP_POSE_TILT_MARGIN_DEG = 5.0
_IMU_TILT_SETTLE_CONSECUTIVE_SAMPLES = 6
_IMU_TILT_SETTLE_POLL_S = 0.02
_DEFAULT_FALL_TILT_DEG = 45.0
_RUN_POLICY_LOG_DIR = Path(__file__).resolve().parents[3] / "_run_policy_logs"
_STANDING_LAYOUT_IDS = {
    "wr_obs_v1", "wr_obs_v9_standing", "wr_obs_v10_standing_recovery"
}
_WALKING_LAYOUT_IDS = {
    "wr_obs_v8_cmd3d",
    "wr_obs_v11_cmd3d_proprio",
    "wr_obs_v12_tb_proprio",
}


class _LogStream:
    def __init__(
        self,
        console_stream: TextIO,
        log_stream: TextIO,
        *,
        mirror_console: bool,
    ):
        self._console_stream = console_stream
        self._log_stream = log_stream
        self._mirror_console = bool(mirror_console)

    @property
    def encoding(self):
        return getattr(self._console_stream, "encoding", "utf-8")

    @property
    def errors(self):
        return getattr(self._console_stream, "errors", "replace")

    def write(self, text: str) -> int:
        self._log_stream.write(text)
        self._log_stream.flush()
        if self._mirror_console:
            self._console_stream.write(text)
            self._console_stream.flush()
        return len(text)

    def flush(self) -> None:
        self._log_stream.flush()
        if self._mirror_console:
            self._console_stream.flush()

    def isatty(self) -> bool:
        return self._mirror_console and bool(self._console_stream.isatty())


def _policy_requires_footswitches(spec) -> bool:
    if str(spec.observation.layout_id) == "wr_obs_v10_standing_recovery":
        return True
    return any(field.name == "foot_switches" for field in spec.observation.layout)


def _validate_footswitch_configuration(
    *,
    enabled: bool,
    policy_specs: Sequence[tuple[str, object]],
) -> None:
    if enabled:
        return
    required_roles = [
        role for role, spec in policy_specs if _policy_requires_footswitches(spec)
    ]
    if required_roles:
        raise SystemExit(
            "Hardware foot switches are disabled, but these active policies "
            f"require foot-contact input: {required_roles}. Re-enable the switches "
            "before running them."
        )


class _TargetBlendRobotIO:
    """Blend initial walking writes from the final standing target."""

    def __init__(self, robot_io, *, initial_target: np.ndarray, blend_steps: int):
        self._robot_io = robot_io
        self.actuator_names = list(robot_io.actuator_names)
        self._initial_target = np.asarray(initial_target, dtype=np.float32).reshape(-1)
        if self._initial_target.size != len(self.actuator_names):
            raise ValueError(
                "initial blend target size does not match hardware actuator count"
            )
        self._blend_steps = max(0, int(blend_steps))
        self._write_step = 0
        self.last_commanded_q_rad = self._initial_target.copy()

    def read(self):
        return self._robot_io.read()

    def write_ctrl(self, target_q_rad: np.ndarray) -> None:
        target = np.asarray(target_q_rad, dtype=np.float32).reshape(-1)
        if self._write_step < self._blend_steps:
            scale = float(self._write_step + 1) / float(self._blend_steps)
            target = self._initial_target + np.float32(scale) * (
                target - self._initial_target
            )
        self._write_step += 1
        self.last_commanded_q_rad = target.astype(np.float32)
        self._robot_io.write_ctrl(self.last_commanded_q_rad)

    def __getattr__(self, name: str):
        return getattr(self._robot_io, name)


class _PolicySubsetRobotIO:
    """Expose policy actuators while holding excluded hardware joints at home."""

    def __init__(
        self,
        robot_io,
        *,
        policy_actuator_names: Sequence[str],
        hardware_actuator_names: Sequence[str],
        hardware_home_q_rad: np.ndarray,
        observation_actuator_names: Sequence[str] | None = None,
    ) -> None:
        self._robot_io = robot_io
        self.actuator_names = list(policy_actuator_names)
        full_names = list(hardware_actuator_names)
        index_by_name = {name: idx for idx, name in enumerate(full_names)}
        missing = [name for name in self.actuator_names if name not in index_by_name]
        if missing:
            raise ValueError(f"Policy actuators missing from hardware plan: {missing}")
        self._policy_indices = np.asarray(
            [index_by_name[name] for name in self.actuator_names], dtype=np.int32
        )
        self.observation_actuator_names = list(
            observation_actuator_names or self.actuator_names
        )
        missing_observed = [
            name for name in self.observation_actuator_names if name not in index_by_name
        ]
        if missing_observed:
            raise ValueError(
                f"Observation actuators missing from hardware plan: {missing_observed}"
            )
        self._observation_indices = np.asarray(
            [index_by_name[name] for name in self.observation_actuator_names],
            dtype=np.int32,
        )
        self._full_home = np.asarray(hardware_home_q_rad, dtype=np.float32).reshape(-1)
        if self._full_home.size != len(full_names):
            raise ValueError("Hardware home length does not match actuator plan")
        self.last_commanded_q_rad = self._full_home[self._policy_indices].copy()

    def read(self):
        signals = self._robot_io.read()
        return type(signals)(
            quat_wxyz=signals.quat_wxyz,
            gyro_rad_s=signals.gyro_rad_s,
            joint_pos_rad=np.asarray(signals.joint_pos_rad)[self._observation_indices],
            joint_vel_rad_s=np.asarray(signals.joint_vel_rad_s)[self._observation_indices],
            foot_switches=signals.foot_switches,
            timestamp_s=signals.timestamp_s,
        )

    def write_ctrl(self, target_q_rad: np.ndarray) -> None:
        target = np.asarray(target_q_rad, dtype=np.float32).reshape(-1)
        if target.size != len(self.actuator_names):
            raise ValueError(
                f"Policy target has {target.size} elements, expected "
                f"{len(self.actuator_names)}"
            )
        full_target = self._full_home.copy()
        full_target[self._policy_indices] = target
        self.last_commanded_q_rad = target.copy()
        self._robot_io.write_ctrl(full_target)

    @property
    def last_servo_diagnostics(self) -> dict[str, np.ndarray]:
        diagnostics = getattr(self._robot_io, "last_servo_diagnostics", {})
        if not isinstance(diagnostics, dict):
            return {}
        projected: dict[str, np.ndarray] = {}
        for key, value in diagnostics.items():
            array = np.asarray(value)
            if array.ndim == 1 and array.size == self._full_home.size:
                array = array[self._policy_indices]
            projected[str(key)] = array.copy()
        return projected

    def __getattr__(self, name: str):
        return getattr(self._robot_io, name)


@contextlib.contextmanager
def _output_log_context(log_path: Optional[str], *, mirror_console: bool):
    if log_path is None:
        yield
        return

    path = Path(log_path).expanduser()
    if path.parent != Path("."):
        path.parent.mkdir(parents=True, exist_ok=True)

    with path.open("w", encoding="utf-8") as log_stream:
        stdout = _LogStream(sys.stdout, log_stream, mirror_console=mirror_console)
        stderr = _LogStream(sys.stderr, log_stream, mirror_console=mirror_console)
        with contextlib.redirect_stdout(stdout), contextlib.redirect_stderr(stderr):
            yield


def _bundle_log_tokens(bundle_path: str, *, stable_only: bool) -> tuple[str, str]:
    stem = Path(bundle_path).expanduser().name.lower()
    role = "stand(?:ing)?" if stable_only else "walk(?:ing)?"
    match = re.search(rf"{role}[_-]?(v\d+)[_-](ckpt\d+)", stem)
    if match is None:
        match = re.search(r"(v\d+).*?(ckpt\d+)", stem)
    if match is not None:
        return match.group(1), match.group(2)

    safe_stem = re.sub(r"[^a-z0-9]+", "-", stem).strip("-") or "bundle"
    return safe_stem, "ckpt-unknown"


def _default_run_policy_log_path(
    bundle_path: str,
    *,
    stable_only: bool,
    log_dir: Path | None = None,
    now: dt.datetime | None = None,
) -> Path:
    version, checkpoint = _bundle_log_tokens(bundle_path, stable_only=stable_only)
    mode = "stable" if stable_only else "walk"
    timestamp = (now or dt.datetime.now().astimezone()).strftime(
        "%Y%m%d_%H%M%S_%f"
    )
    root = _RUN_POLICY_LOG_DIR if log_dir is None else Path(log_dir)
    return root / f"{version}_{checkpoint}_{mode}_{timestamp}.log"


def _resolve_telemetry_path(value: Optional[str], log_path: Path) -> Path | None:
    if value is None:
        return None
    path = log_path.with_suffix(".npz") if value == "" else Path(value).expanduser()
    if path.suffix != ".npz":
        raise SystemExit("--telemetry output path must end in .npz")
    return path


def _create_telemetry_recorder(
    args: argparse.Namespace,
    *,
    actuator_names: Sequence[str],
    ctrl_dt: float,
    bundle_path: Path,
    hardware_config_path: Path,
) -> PolicyTelemetryRecorder | None:
    telemetry_path = getattr(args, "telemetry_path", None)
    if telemetry_path is None:
        return None
    recorder = PolicyTelemetryRecorder(
        telemetry_path,
        actuator_names=actuator_names,
        ctrl_dt=ctrl_dt,
        bundle_path=bundle_path,
        hardware_config_path=hardware_config_path,
    )
    args.telemetry_recorder = recorder
    print(f"Policy telemetry enabled: {telemetry_path}", flush=True)
    return recorder


def _close_robot_io_with_telemetry(robot_io, telemetry) -> None:
    """Close hardware, then preserve the unload/verification report in telemetry."""
    try:
        robot_io.close()
    finally:
        if telemetry is not None:
            telemetry.record_shutdown(
                getattr(robot_io, "last_shutdown_diagnostics", {})
            )


def _install_stack_dump_signal() -> None:
    sigusr1 = getattr(signal, "SIGUSR1", None)
    if sigusr1 is None:
        return
    try:
        faulthandler.register(sigusr1, file=sys.stderr, all_threads=True)
    except Exception:
        pass


def _parse_velocity_cmd(text: Optional[str], default: List[float]) -> np.ndarray:
    if text is None:
        return np.asarray(default, dtype=np.float32).reshape(3)
    parts = [p.strip() for p in str(text).split(",") if p.strip() != ""]
    if len(parts) == 1:
        return np.array([float(parts[0]), 0.0, 0.0], dtype=np.float32)
    if len(parts) == 3:
        return np.array([float(p) for p in parts], dtype=np.float32)
    raise SystemExit(
        f"--velocity-cmd must be 'vx' or 'vx,vy,wz'; got {text!r}"
    )


def _load_optional_runtime_control_dt(bundle_path: Path, *, default: float = 0.02) -> float:
    path = bundle_path / "runtime_policy_config.json"
    if not path.exists():
        return float(default)
    try:
        data = json.loads(path.read_text())
    except Exception:
        return float(default)
    if isinstance(data, dict):
        if data.get("ctrl_dt") is not None:
            return float(data["ctrl_dt"])
        if data.get("control_hz") is not None and float(data["control_hz"]) > 0.0:
            return 1.0 / float(data["control_hz"])
    return float(default)


def _default_velocity_cmd_for_layout(spec, runtime_config: RuntimePolicyConfig | None) -> list[float]:
    if runtime_config is not None:
        return list(runtime_config.default_velocity_cmd)
    if spec.observation.layout_id in _STANDING_LAYOUT_IDS:
        return [0.0, 0.0, 0.0]
    raise SystemExit(
        "runtime_policy_config.json is required for this policy layout; "
        f"got layout={spec.observation.layout_id!r}"
    )


def _resolve_run_bundle_path(
    *, bundle_arg: Optional[str], stable_only: bool
) -> Path:
    if bundle_arg is None:
        raise SystemExit("--bundle is required.")
    return Path(bundle_arg)


def _resolve_hardware_config_path(hardware_config_arg: Optional[str]) -> Path:
    from configs import DEFAULT_HARDWARE_CONFIG_PATH

    if hardware_config_arg is not None:
        return Path(hardware_config_arg)
    return DEFAULT_HARDWARE_CONFIG_PATH


def _policy_loop_max_steps(
    *, stable_only: bool, dry_run: bool, max_steps: int
) -> int | None:
    """Run real stable-only control until the operator interrupts it."""
    if stable_only and not dry_run:
        return None
    return int(max_steps)


def _startup_home_hold_steps(
    *,
    stable_only: bool,
    dry_run: bool,
    command_norm: float,
    command_deadzone: float,
    duration_s: float,
    ctrl_dt: float,
) -> int:
    """Return startup preparation steps for standing or commanded walking."""
    if bool(dry_run) or float(duration_s) <= 0.0:
        return 0
    if not bool(stable_only) and float(command_norm) <= float(command_deadzone):
        return 0
    return max(1, int(round(float(duration_s) / max(float(ctrl_dt), 1e-9))))


def _adaptive_startup_pose_blend(
    *,
    initial_q_rad: np.ndarray,
    home_q_rad: np.ndarray,
    minimum_duration_s: float,
    ctrl_dt: float,
) -> tuple[int, float, float]:
    """Choose a 2--3 s pose blend from the largest measured joint delta."""
    initial = np.asarray(initial_q_rad, dtype=np.float32).reshape(-1)
    home = np.asarray(home_q_rad, dtype=np.float32).reshape(-1)
    if initial.shape != home.shape:
        raise ValueError(
            f"startup pose shapes differ: initial={initial.shape}, home={home.shape}"
        )
    max_delta_deg = float(np.rad2deg(np.max(np.abs(home - initial))))
    minimum_s = max(0.0, float(minimum_duration_s))
    if minimum_s <= 0.0:
        return 0, max_delta_deg, 0.0
    maximum_s = max(minimum_s, _STARTUP_POSE_BLEND_MAX_S)
    duration_s = min(
        maximum_s,
        max(minimum_s, max_delta_deg / _STARTUP_POSE_BLEND_RATE_DEG_S),
    )
    steps = max(1, int(round(duration_s / max(float(ctrl_dt), 1e-9))))
    return steps, max_delta_deg, steps * float(ctrl_dt)


def _startup_preparation_tilt_limit_deg(
    *,
    initial_quat_wxyz: np.ndarray,
    final_stability_max_tilt_deg: float,
    walking_fall_tilt_deg: float,
) -> float:
    tilt_rad = _quat_wxyz_tilt_rad(initial_quat_wxyz)
    initial_tilt_deg = 0.0 if tilt_rad is None else float(math.degrees(tilt_rad))
    return min(
        _STARTUP_POSE_HARD_MAX_TILT_DEG,
        max(
            float(final_stability_max_tilt_deg),
            float(walking_fall_tilt_deg),
            initial_tilt_deg + _STARTUP_POSE_TILT_MARGIN_DEG,
        ),
    )


def _native_17d_runtime_plan(
    spec, *, policy_role: str
) -> tuple[list[str], np.ndarray, np.ndarray, np.ndarray]:
    """Return the direct policy-to-hardware plan for a native 17D policy."""
    active_names = list(spec.robot.actuator_names)
    if int(spec.model.action_dim) != 17 or len(active_names) != 17:
        raise SystemExit(
            f"{policy_role} policy must use the native 17-actuator contract; "
            f"got action_dim={spec.model.action_dim}, actuators={len(active_names)}"
        )
    wrist_names = [name for name in active_names if "wrist" in name]
    if wrist_names:
        raise SystemExit(
            f"{policy_role} policy contains deprecated wrist actuators: {wrist_names}"
        )
    if spec.robot.home_ctrl_rad is None:
        raise SystemExit(f"{policy_role} policy_spec.robot.home_ctrl_rad is required")
    active_home = np.asarray(spec.robot.home_ctrl_rad, dtype=np.float32).reshape(-1)
    if active_home.size != len(active_names):
        raise SystemExit(
            f"home_ctrl_rad length {active_home.size} != active actuator count "
            f"{len(active_names)}"
        )

    return (
        active_names,
        active_home,
        np.asarray(
            [spec.robot.joints[name].range_min_rad for name in active_names],
            dtype=np.float32,
        ),
        np.asarray(
            [spec.robot.joints[name].range_max_rad for name in active_names],
            dtype=np.float32,
        ),
    )


def _walking_runtime_plan(spec):
    fixed = (spec.provenance or {}).get("runtime_fixed_home")
    if not isinstance(fixed, dict):
        return _native_17d_runtime_plan(spec, policy_role="walking")

    active_names = list(spec.robot.actuator_names)
    full_names = [str(name) for name in fixed.get("full_actuator_names", [])]
    fixed_names = [str(name) for name in fixed.get("fixed_actuator_names", [])]
    if active_names != [
        str(name) for name in fixed.get("active_actuator_names", [])
    ]:
        raise SystemExit("runtime_fixed_home active actuator order is inconsistent")
    if not full_names or set(full_names) != set(active_names) | set(fixed_names):
        raise SystemExit("runtime_fixed_home does not define the full actuator set")

    fixed_home_values = [float(v) for v in fixed.get("fixed_home_ctrl_rad", [])]
    if len(fixed_home_values) != len(fixed_names):
        raise SystemExit("runtime_fixed_home fixed actuator/home lengths differ")
    if spec.robot.home_ctrl_rad is None:
        raise SystemExit("walking policy_spec.robot.home_ctrl_rad is required")
    home_by_name = dict(zip(active_names, spec.robot.home_ctrl_rad))
    home_by_name.update(dict(zip(fixed_names, fixed_home_values)))
    fixed_ranges = dict(fixed.get("fixed_joint_ranges_rad", {}))

    def _range(name: str) -> tuple[float, float]:
        if name in spec.robot.joints:
            joint = spec.robot.joints[name]
            return float(joint.range_min_rad), float(joint.range_max_rad)
        values = fixed_ranges.get(name)
        if not isinstance(values, list) or len(values) != 2:
            raise SystemExit(f"runtime_fixed_home missing range for {name}")
        return float(values[0]), float(values[1])

    ranges = [_range(name) for name in full_names]
    return (
        full_names,
        np.asarray([home_by_name[name] for name in full_names], dtype=np.float32),
        np.asarray([item[0] for item in ranges], dtype=np.float32),
        np.asarray([item[1] for item in ranges], dtype=np.float32),
    )


def _standing_runtime_plan(spec):
    return _native_17d_runtime_plan(spec, policy_role="standing")
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

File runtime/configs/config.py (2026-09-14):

"""Runtime configuration for WildRobot hardware deployment.

This module provides a structured configuration class for running the WildRobot
policy on real hardware. Configuration is loaded from a JSON file that specifies:
- Policy and model paths
- Control loop parameters
- Servo controller settings (port, servo IDs, joint offsets)
- BNO085 IMU settings
- Foot switch GPIO pins

Usage:
    from configs import WrRuntimeConfig

    # Load from runtime/configs/hardware_config.json
    config = WrRuntimeConfig.load()

    # Load from specific path
    config = WrRuntimeConfig.load("/path/to/config.json")

    # Access nested config
    print(config.control.hz)  # 50.0
    print(config.hiwonder_controller.get_servo_id("left_hip_pitch"))  # 1
    print(config.bno085.transport)  # "i2c" or "spi"
"""

from __future__ import annotations

import json
import math
from dataclasses import dataclass, field
from pathlib import Path
from typing import Dict, List, Optional, Tuple


import yaml


# =============================================================================
# Default paths
# =============================================================================

DEFAULT_HARDWARE_CONFIG_PATH = Path(__file__).resolve().parent / "hardware_config.json"

# Default robot_config path (joint ranges, mirror signs, etc.)
# Current assets layout is v2.
DEFAULT_ROBOT_CONFIG_PATH = Path("assets/v2/mujoco_robot_config.json")

LEFT_LEG_BOARD = "left_leg_board"
RIGHT_LEG_BOARD = "right_leg_board"
UPPER_BODY_BOARD = "upper_body_board"
SERVO_BOARD_NAMES = (LEFT_LEG_BOARD, RIGHT_LEG_BOARD, UPPER_BODY_BOARD)


def servo_board_name_for_joint(joint_name: str) -> str:
    """Return the fixed physical board role for a configured joint."""
    name = str(joint_name)
    is_leg_joint = any(part in name for part in ("hip", "knee", "ankle"))
    if name.startswith("left_") and is_leg_joint:
        return LEFT_LEG_BOARD
    if name.startswith("right_") and is_leg_joint:
        return RIGHT_LEG_BOARD
    return UPPER_BODY_BOARD


# =============================================================================
# Nested Configuration Dataclasses
# =============================================================================


@dataclass(frozen=True)
class ControlConfig:
    """Control loop configuration.

    Attributes:
        hz: Control loop frequency in Hz (default: 50)
        action_scale_rad: Scale factor for policy actions in radians (default: 0.35)
        velocity_cmd: Initial forward-speed command for the policy in m/s (default: 0.0)
        yaw_rate_cmd: Initial yaw-rate command for the policy in rad/s (default: 0.0)
    """

    hz: float = 50.0
    action_scale_rad: float = 0.35
    velocity_cmd: float = 0.0
    yaw_rate_cmd: float = 0.0

    @property
    def dt(self) -> float:
        """Control loop period in seconds."""
        return 1.0 / self.hz


@dataclass(frozen=True)
class ServoConfig:
    """Configuration for a single servo.

    Attributes:
        id: Servo ID (1-254)
        servo_offset_unit: Calibration offset in servo units (default: 0)
        motor_unit_direction: Hardware motor direction correction (+1 or -1, default: +1)
        joint_angle_at_servo_center_deg: MuJoCo angle (deg) that maps to the servo-unit center
            (servo_unit == 500) when offset==0.
        rad_range: Joint range in radians (min, max) from mujoco_robot_config.json
        max_velocity: Maximum joint velocity in rad/s from mujoco_robot_config.json
    """

    id: int
    servo_offset_unit: int = 0
    motor_unit_direction: float = 1.0
    joint_angle_at_servo_center_deg: float = 0.0
    rad_range: Tuple[float, float] = (0.0, 0.0)
    max_velocity: float = 10.0

    # Servo conversion constants
    # Hiwonder HTD-45H: 240° range = 4.1887902 rad, units [0, 1000], center at 500
    UNITS_MIN: int = 0
    UNITS_MAX: int = 1000
    UNITS_CENTER: int = 500
    RANGE_RAD: float = 4.1887902047863905  # 240 degrees in radians
    UNITS_PER_RAD: float = 1000.0 / 4.1887902047863905  # ~238.73

    @property
    def offset_unit(self) -> int:
        return int(self.servo_offset_unit)

    @property
    def offset(self) -> int:
        return int(self.servo_offset_unit)

    @property
    def servo_offset(self) -> int:
        return int(self.servo_offset_unit)

    @property
    def motor_sign(self) -> float:
        return float(self.motor_unit_direction)

    @property
    def servo_unit_direction(self) -> float:
        return float(self.motor_unit_direction)

    @property
    def motor_center_mujoco_deg(self) -> float:
        return float(self.joint_angle_at_servo_center_deg)

    @property
    def center_rad(self) -> float:
        return math.radians(float(self.joint_angle_at_servo_center_deg))

    def joint_target_rad_to_elect_unit(self, target_rad: float) -> int:
        """Convert MuJoCo radians to servo units.
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

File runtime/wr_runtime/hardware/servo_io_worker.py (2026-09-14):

from __future__ import annotations

import math
import threading
import time
from dataclasses import dataclass, replace
from logging import Logger
from typing import Optional, Sequence

import numpy as np

from .hiwonder_ttl_bus import RawServoBus


@dataclass(frozen=True)
class ServoReadGroup:
    name: str
    servo_ids: tuple[int, ...]
    retry_cache_age_s: float | None = None
    max_cache_age_s: float | None = None


@dataclass(frozen=True)
class ServoIOWorkerConfig:
    servo_ids: tuple[int, ...] = ()
    read_groups: tuple[ServoReadGroup, ...] = ()
    read_group_schedule: tuple[str, ...] = ()
    max_write_attempts: int = 2
    write_deadband_units: int = 3
    max_read_attempts: int = 2
    retry_cache_age_s: float = 0.08
    max_cache_age_s: float = 0.25
    min_reads_after_write: int = 2
    idle_sleep_s: float = 0.0005
    stale_log_period_s: float = 1.0
    health_poll_interval_s: float = 0.0


@dataclass(frozen=True)
class CachedServoState:
    servo_ids: tuple[int, ...]
    position_units: np.ndarray
    velocity_units_s: np.ndarray
    position_age_s: np.ndarray
    read_fail_count: np.ndarray
    last_update_time_s: np.ndarray
    temperature_c: np.ndarray
    voltage_v: np.ndarray
    torque_enabled_state: np.ndarray
    temperature_age_s: np.ndarray
    voltage_age_s: np.ndarray
    torque_enabled_age_s: np.ndarray
    health_read_fail_count: np.ndarray
    last_read_group: str | None
    last_read_servo_id: int | None
    last_error: str | None


@dataclass(frozen=True)
class ServoIOMetrics:
    write_targets_submitted: int = 0
    write_targets_replaced: int = 0
    write_commands: int = 0
    write_commands_skipped: int = 0
    write_failures: int = 0
    cache_deadline_reads: int = 0
    forced_read_after_write: int = 0
    forced_read_after_write_missed: int = 0
    read_success: int = 0
    read_failures: int = 0
    stale_cache_errors: int = 0
    health_read_success: int = 0
    health_read_failures: int = 0
    unexpected_unload_events: int = 0
    unload_commands: int = 0
    unload_failures: int = 0
    unload_unverified: int = 0
    latest_write_queue_latency_s: float = 0.0
    latest_write_latency_s: float = 0.0
    latest_read_latency_s: float = 0.0
    latest_health_read_latency_s: float = 0.0


class ServoIOWorker:
    """Single-owner runtime IO worker for raw HTD/Hiwonder servo buses.

    The worker accepts latest-wins target writes and otherwise polls one servo
    position at a time into a full cache. Optional health reads are individually
    staggered across the configured interval and yield to target writes and
    position-cache deadlines; the worker never performs a blocking health sweep.
    """

    _CACHE_DEADLINE_READ_FRACTION = 0.70
    _HEALTH_FIELDS = ("temperature", "voltage", "torque_enabled")

    def __init__(
        self,
        raw_bus: RawServoBus,
        config: ServoIOWorkerConfig,
        *,
        logger: Logger | None = None,
        worker_name: str = "servo_board",
    ) -> None:
        self.raw_bus = raw_bus
        self.config = config
        self.logger = logger
        self.worker_name = str(worker_name)

        self._read_groups = self._normalize_read_groups(config)
        self._read_group_by_name = {group.name: group for group in self._read_groups}
        self._schedule = self._normalize_schedule(config, self._read_groups)
        self._group_offsets = {group.name: 0 for group in self._read_groups}
        self._schedule_index = 0

        servo_ids = self._servo_ids_from_config(config, self._read_groups)
        if not servo_ids:
            raise ValueError("ServoIOWorker requires at least one servo id")
        self.servo_ids = tuple(servo_ids)
        self._id_to_index = {sid: i for i, sid in enumerate(self.servo_ids)}
        self._group_for_servo = self._build_group_for_servo(self._read_groups)
        self._max_cache_age_by_servo = self._build_max_cache_age_by_servo(
            self.servo_ids, self._read_groups, config
        )

        n = len(self.servo_ids)
        self._position_units = np.full(n, np.nan, dtype=np.float32)
        self._velocity_units_s = np.zeros(n, dtype=np.float32)
        self._last_update_time_s = np.full(n, np.nan, dtype=np.float64)
        self._read_fail_count = np.zeros(n, dtype=np.int32)
        self._temperature_c = np.full(n, np.nan, dtype=np.float32)
        self._voltage_v = np.full(n, np.nan, dtype=np.float32)
        self._torque_enabled_state = np.full(n, -1, dtype=np.int8)
        self._torque_disabled_active = np.zeros(n, dtype=bool)
        self._temperature_update_time_s = np.full(n, np.nan, dtype=np.float64)
        self._voltage_update_time_s = np.full(n, np.nan, dtype=np.float64)
        self._torque_enabled_update_time_s = np.full(n, np.nan, dtype=np.float64)
        self._health_read_fail_count = np.zeros(n, dtype=np.int32)

        self._lock = threading.Lock()
        self._wake = threading.Event()
        self._stop = threading.Event()
        self._thread: threading.Thread | None = None
        self._pending_target: tuple[dict[int, int], int, float] | None = None
        self._retry_queue: list[int] = []
        self._retry_attempts: dict[int, int] = {}
        self._stale_log_time: dict[int, float] = {}
        self._last_read_group: str | None = None
        self._last_read_servo_id: int | None = None
        self._last_error: str | None = None
        self._last_written_target_by_servo: dict[int, tuple[int, int]] = {}
        self._health_cursor = 0
        self._next_health_read_s = time.monotonic()
        self._metrics = ServoIOMetrics()

    @staticmethod
    def _normalize_read_groups(config: ServoIOWorkerConfig) -> tuple[ServoReadGroup, ...]:
        if config.read_groups:
            return tuple(config.read_groups)
        if config.servo_ids:
            return (ServoReadGroup(name="all", servo_ids=tuple(config.servo_ids)),)
        return ()
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

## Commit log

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2025-11-28 update wildrobot xml, fix hip angle
    [batterybox.stl, btm_servo_support.stl, foot_btm_front.stl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]
2025-11-30 fix for new training
    [phase1_contact.yaml]
2025-12-01 [amp] Phase 1G: Fix exp(-error²) local minimum with Option 3 (hybrid fix)
    Phase 1E and 1F both failed - robot degraded from 0.55 m/s to near-zero despite
    learning to walk initially. Root cause: exp(-error²) gives 61% reward for 100% error,
    making standing still (reward +9.3) more attractive than walking (reward +101.4).
    This diff implements Option 3 (Hybrid Fix) with two critical changes:
    FIX #1: Stricter tracking formula
    - OLD: tracking_lin_xy = exp(-error²) → 61% reward for 100% error
    - NEW: tracking_lin_xy = exp(-3.0 × error²) → 23% reward for 100% error
    - Reduces standing reward from 9.2 to 3.5 (-62%)
    FIX #2: Velocity threshold penalty
    - NEW: penalty = -50.0 × max(0, 0.3 - v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
    [phase1_contact.yaml]
2025-12-01 [amp] Phase 1G-v2: Reduce velocity threshold penalty (Option 3 gentler)
    Phase 1G FAILED after 4.6% with velocity_threshold_penalty=-17.61, reward=-9.09.
    Robot trapped in punishment zone, couldn't escape to higher velocities.
    Root cause: Penalty too harsh and threshold too high
    - velocity_threshold: 0.3 m/s (unreachable from 0.1 m/s start)
    - velocity_threshold_penalty: 50.0 (dominated all rewards: -17.61 penalty vs +12.81 total rewards)
    Phase 1G-v2 FIX: Gentler parameters (Option A)
    - velocity_threshold: 0.3 → 0.15 m/s (achievable from start)
    - velocity_threshold_penalty: 50.0 → 25.0 (half as harsh)
    Expected impact:
    - At 0.7 m/s: reward +101.4 (unchanged)
    Key differences:
    - Phase 1G: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
    [phase1_contact.yaml]
2025-12-01 [amp] Fix scp_to_remote.sh --amp to preserve directory structure
    Issue: Files in subdirectories (e.g., tests/) were being copied directly
    to remote amp/ folder without preserving the directory structure.
    Root cause: scp -r doesn't preserve directory structure when copying
    individual files. When copying ./tests/test.py, scp just copies the file
    itself to the destination, not the tests/ folder.
    Fix: Replace scp with rsync --relative
    - rsync --relative preserves the path from current directory
    - Example: ./tests/test_env_contracts.py → remote:~/amp/tests/test_env_contracts.py
    - Works for both local network and public IP (--public flag)
    Benefits:
    - Maintains correct project structure on rem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
2025-12-15 complete task 10 phase 2
    🎉 Task 10 Phase 2 Successfully Completed!
    Summary of Accomplishments
    What we fixed (in order):
    ✅ Removed wrap_for_training parameter (doesn't exist in Brax API)
    ✅ Rewrote wrapper to use Pure-JAX backend (no numpy operations)
    ✅ Fixed environment batching (single-env wrapper, Brax handles vmap)
    ✅ Resolved vmap in_axes mismatch (used non-vmapped step function)
    ✅ Padded ctrl dimension (11→17 for pytree consistency)
    ✅ Fixed dtype issue (done must be float32, not bool)
    ✅ Preserved state.metrics dict structure
    Result: Smoke test PASSED! (10 iterations, 4 envs, 4.1 seconds)
    Key Technical Breakthrough
    The critical insight was understanding Brax's scalar d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
2025-12-15 Task 10 complete
    Task 10 Phase 3: COMPLETE ✅
    Training Results
    Status: ✅ Training pipeline working end-to-end
    Duration: 8.4 seconds (100,000 timesteps, 16 envs)
    Checkpoint: Valid, policy parameters updated
    Metrics:
    Reward: -33.43 (expected for untrained policy)
    Policy loss: -0.000277 (training occurring)
    Config preserved correctly
    Key Finding: The episode length being 0.0 is EXPECTED - the robot falls immediately with an untrained policy (zero control + gravity). This is normal PPO initialization behavior.
    What This Proves
    ✅ Training pipeline validated:
    Environment creates correctly
    Brax PPO trains successfully
    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
2025-12-20 fix training
    [wildrobot_phase3_training.yaml]
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2025-12-21 fix training params
    [wildrobot_phase3_training.yaml]
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2025-12-21 Update params for training:
    Changes Summary
    🔧 Config (wildrobot_phase3_training.yaml)
    Setting Before After
    rollout_steps 20 128
    ref_seq_len 32 16
    tracking_lin_vel 2.0 5.0
    label_smoothing 0.1 0.2
    disc_input_noise_std 0.02 0.05
    Config structure Verbose Simplified
    🤖 Environment (wildrobot_env.py)
    ✅ Auto-reset on termination
    ✅ Sharper velocity reward (exp(-error × 4.0))
    ✅ Forward movement bonus (+0.3 × vel)
    ⚡ Trainer (trainer_jit.py)
    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
    [wildrobot_phase3_training.yaml]
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2025-12-22 Summary: Simplified Checkpoint System Changes Made Removed best_checkpoint_* file generation - No longer creates separate best checkpoint files
    Updated checkpoint.py:
    Removed list_best_checkpoints() function
    Added get_top_checkpoints_by_reward() - Parses all checkpoints and returns top N by reward
    Renamed print_best_checkpoints_summary() → print_top_checkpoints_summary()
    Simplified manage_checkpoints() - Only cleans regular checkpoints now
    Simplified callback in train.py:
    Still tracks best-in-window for saving (most performant checkpoint within each window)
    Removed is_best flag since we don't generate best checkpoint files anymore
    New Output at End of Training
    🏆 Top 3 Checkpoints (by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
2025-12-23 Current Config Summary (All Changes This Session) Parameter Before After Effect AMP Reward log(sigmoid(D)) penalty max(0, 1-0.25*(D-1)²) bonus Positive reward (0→1) Normalization Running stats (drift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
    AMP contribution: ~35-40% of total reward
    The policy should now stron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
    [config.py]
2025-12-23 Changes to ppo_amass_training.yaml Parameter Before After Reason tracking_lin_vel 1.5 5.0 Stronger velocity incentive - robot must move to get reward amp.weight 1.0 0.5 Reduced to balance with veloci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
    Discriminator accuracy changing (moving away from 50%) - proves it's learning
    Velocity increasing (from 0.03 m/s toward 0.3-0.8 m/s target)
    Reward pattern changing - init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
2025-12-23 Updated. Here's the summary:
    Parameter Before After Effect
    amp.disc_lr 1e-4 2e-5 Slow discriminator learning (5x slower)
    amp.update_steps 4 1 One disc update per policy update
    amp.gradient_penalty_weight 10.0 30.0 Smoother gradients for clearer signals
    amp.disc_input_noise_std 0.02 0.05 More blur to prevent overfitting
    amp.weight 0.5 0.3 Lower style pressure
    These changes collectively handicap the discriminator so the policy can catch up. Expected result: disc_acc should drop from ~0.97 toward ~0.7 over time.
2025-12-23 Updated. Summary of middle-ground settings:
    Parameter Was (collapsed) Now Target
    disc_lr 2e-5 5e-5 Faster learning
    update_steps 1 2 More disc updates
    gradient_penalty_weight 30.0 15.0 Less regularization
    disc_input_noise_std 0.05 0.05 (kept)
    Goal: disc_acc oscillating between 0.6-0.8 (discriminator learning but not dominating)
2025-12-23 Summary of Changes: Velocity Normalization for AMP Training Problem Speed mismatch between reference motion data (~0.27 m/s) and commanded velocity (0.5-1.0 m/s) caused the discriminator to penalize 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
    Solution
    Normalize root linear velocity to unit direction vector, preserving direction while removing speed magnitude.
    Files Modified
    File Change
    amp_features.py
    Added safe velocity normalization with 0.1 m/s threshold
    convert_ref_data_normalized_velocity.py
    Created script to convert reference data
    validate_feature_consistency.py
    Created validation script (new this session)
    reference_data_generation.md
    Updated documentation
    ppo_amass_training.yaml
    Poi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
    [robot_config.yaml]
2025-12-23 Updated ppo_amass_training.yaml with the minibatch fix:
    Changes made:
    version "0.3.0" "0.3.1"
    version_name "Velocity Normalization" "Minibatch Optimization"
    epochs 4 3
    num_minibatches 8 128
    Effect on training:
    Before:
    Minibatch size = 1024 × 128 / 8 = 16,384 ❌
    Updates/iter = 8 × 4 = 32
    After:
    Minibatch size = 1024 × 128 / 128 = 1,024 ✅
    Updates/iter = 128 × 3 = 384
    The minibatch size is now in the optimal PPO range (256-1024), which will improve gradient noise for better exploration and preserve the subtle AMP reward signal.
    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
2025-12-23 Problem Identified The AMP training had a critical bug: the discriminator was comparing misaligned features between policy and reference data due to hardcoded joint order in GMR's conversion scripts.
    Component Expected Order Actual (Bug)
    MuJoCo qpos waist_yaw at index 0 ✅ Correct
    robot_config.yaml waist_yaw at index 0 ✅ Correct
    GMR convert_to_amp_format.py Hardcoded left_hip_pitch at index 0 ❌ Wrong
    Reference data joint_names left_hip_pitch at index 0 ❌ Wrong
    Additionally, estimate_foot_contacts() used wrong indices (e.g., dof_pos[:, 0] for left_hip_pitch when it should be index 1).
    Solution: Config-Driven Pipeline (No Hardcoding)
    GMR Changes (
    scripts
    )
    convert_to_amp_format.py:
    A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
    [robot_config.yaml]
2025-12-23 All tasks completed. Here's a summary of the changes:
    ✅ v0.4.0 "Critical Bug Fixes" - Implementation Complete
    File Changes
    discriminator.py
    Fixed reward formula: jnp.clip(scores, 0, 1) instead of quadratic
    trainer_jit.py
    Fixed training order: compute rewards BEFORE training discriminator
    Updated to v0.4.0, network size [512, 256]
    phase3_rl_training_plan.md
    Added TODO section for P2/P3 improvements
    AMP_DISCRIMINATOR_DESIGN_REVIEW.md
    Updated to v2.0 with external feedback
    Fix Before After
    Reward Formula max(0, 1 - 0.25*(D-1)²) → D=0 gives 0.75 clip(D, 0, 1) → D=0 gives 0.00
    Training Order Reward uses NEW disc params Reward uses OLD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
2025-12-23 Current Status: v0.4.1 "R1 Regularizer" ✅ Complete Implemented fixes:
    P0 - Reward Formula: Changed from quadratic to clipped linear (jnp.clip(scores, 0.0, 1.0))
    P0 - Training Order: Compute AMP rewards with OLD disc_params BEFORE discriminator update
    P1 - Network Size: Increased to [512, 256]
    P1 - R1 Regularizer: Replaced WGAN-GP with R1 regularization for LSGAN consistency
    Debugging: Added distribution metrics (disc_real_mean, disc_fake_mean, disc_real_std, disc_fake_std)
    Pending P2/P3 TODOs (documented in phase3_rl_training_plan.md):
    P2: Spectral Normalization (~30 min)
    P2: Policy Replay Buffer (~2 hours)
    P3: Temporal Context / 2-3 frames (~4 hours)
    P3: Fix foot contact features (~4 hou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
2025-12-23 v0.5.0 - Foot Contact Fix Problem The AMP discriminator was receiving zeros for foot contacts from policy rollouts while reference data had 88% non-zero contacts. This distribution mismatch meant the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
    Root Cause
    extract_amp_features() silently returned zeros when foot_contacts wasn't provided, hiding the bug.
    Changes
    1. Fail Loudly (No Silent Fallbacks)
    amp_features.py foot_contacts=None → raises ValueError with clear instructions
    wildrobot_env.py Missing foot geoms → raises RuntimeError (was: silent warning + None)
    trainer_jit.py extract_amp_features_batched() now requires foot_contacts para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
    [foot_main.stl, foot_main_right.stl, foot_side_right.stl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]
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2025-12-25 v0.7.0
    Training Config v0.6.6 (wildrobot)
    Fixed root linear velocity: raw m/s instead of normalized direction
    Removed waist masking (27-dim features for 8-joint robot)
    Feature parity between policy and reference
    GMR Scripts v0.7.0 + v0.9.3 (GMR repo)
    v0.7.0: All velocities converted to heading-local frame (rotation invariance)
    v0.9.3: FK-based contact estimation using MuJoCo (fixes 84% double-stance issue)
    Physics Reference Generator (NEW - not versioned yet)
    Full harness mode for dynamically infeasible motions
    Physics-derived contacts from MuJoCo constraint solver
    All 12 motions accepted (3,407 frames, 68.14s)
    [feasibility_report.csv]
2025-12-26 v0.8.0 Completed Features 1. Feature Dropping (Prevent Discriminator Shortcuts) drop_contacts - Drop foot contacts (4 dims) drop_height - Drop root height (1 dim) normalize_velocity - Normalize root_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
2025-12-28 Registry-Based Metrics Refactoring Complete ✅
    Files Changed
    1. playground_amp/training/metrics_registry.py (NEW)
    - Single source of truth for all 31 metrics
    - METRIC_SPECS: List of MetricSpec with name, reducer, prefix, topline flag
    - build_metrics_vec(): Pack dict → fixed-shape array
    - aggregate_metrics(): Reduce (T, N, M) → dict of scalars
    - format_for_wandb(): Apply prefixes for W&B logging
    2. playground_amp/envs/wildrobot_env.py
    - Added metrics_vec field to WildRobotEnvState
    - Both reset() and step() now build metrics_vec from the metrics dict
    - Uses build_metrics_vec() - missing metrics cause KeyError (fail fast)
    3. playground_amp/training/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
2025-12-28 v0.10.4 Final Summary
    Changes from Your Review
    1. Fixed forward_velocity_scale direction
    - Formula: exp(-error * scale) → higher = sharper
    - Changed: 4.0 → 6.0 (not 2.0)
    2. Stronger tracking weight
    - Changed: 2.0 → 8.0
    3. Smooth, robust standing penalty
    # Smooth penalty (not discontinuous)
    velocity_deficit = jp.maximum(threshold - jp.abs(forward_vel), 0.0)
    standing_penalty_raw = velocity_deficit / threshold
    # Gate by |cmd| (supports future backward commands)
    cmd_gate = jp.where(jp.abs(velocity_cmd) > velocity_cmd_min, 1.0, 0.0)
    # Gate by healthy (prevents twitch during falling/recovery)
    healthy_gate = healthy
    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
2025-12-28 v0.10.4 Bug Fixes Summary:
    1. Episode length accumulation bug - ep_len was showing impossible values (>500) because step_count accumulated across episodes instead of
    resetting. Fixed by:
    - Adding episode_step_count metric preserved through auto-reset
    - Resetting wr_info.step_count to 0 on new episode
    2. Tracking metrics not preserved - vel_err=0.000 when velocity=0 and cmd=0.65. Fixed by:
    - Preserving tracking/vel_error, tracking/max_torque, forward_velocity, velocity_command through auto-reset
2025-12-29 Summary of Refactoring
    Problem: The visualization was running at ~10 seconds per step due to MJX on CPU being slow (145ms/step vs target 20ms for 50Hz).
    Solution: Refactored playground_amp/training/visualize_policy.py to use native MuJoCo (C-based) instead of MJX (JAX-based).
    Key Changes:
    1. Removed MJX dependency - Physics now runs via mujoco.mj_step() directly
    2. Used robot_config for sensors - Reads sensor names from robot_config.yaml for consistency with training
    3. Fixed observation format - Uses ObsLayout structure (gravity, angvel, linvel, joint_pos, joint_vel, action, velocity_cmd, padding)
    4. Added action filtering - Applies low-pass filter (alpha=0.7) matching train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
2025-12-31 • Updated CAL and config generation to make HEADING_LOCAL root‑relative, fixed actuator torque indexing, removed obsolete pelvis sensors, hardened mirror‑sign detection, and expanded tests/ docs with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
    Key edits
    - assets/post_process.py: stricter mirror detec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
    [batterybox.stl, foot_btm_front.stl, foot_main.stl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]
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2026-01-01 [v0.11.3] ready for standing training 1. Added height target shaping + stance width penalty to discourage squat posture 2. fix tests, and bugs that identified by tests: Product fixes
    - playground_amp/envs/wildrobot_env.py: reset now uses the default pose action (via ctrl_to_policy_action(self._default_joint_qpos)) for
    prev_action and the observation, ensuring reset action/ctrl/obs consistency.
    - playground_amp/amp/policy_features.py: contact estimation now indexes joints with [..., idx] and stacks contacts with axis=-1, so it supports
    batched inputs and produces (..., 4) contacts.
    Also handles scalar root_height by promoting to (1,) before feature assembly.
    - playground_a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
    [wildrobot.xml]
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2026-01-02 fix the foot btm not symmetric
    [batterybox.stl, bno085.stl, foot_btm_front.stl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]
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2026-01-18 implement runtime acutuator - Added runtime/wr_runtime/hardware/actuators.py with Actuators protocol, HiwonderBoardActuators (rad↔servo conversion, per-joint directions, retries, timing), conversion 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
    Tests run:
    - uv run pytest tests/test_runtime_actuators_co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
    [actuators.py, config.py, robot_io.py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]
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2026-01-22 [Milestone1] Run the first policy 0.12.2 on robot leeygang@wrdev:~/projects/wildrobot $ uv run runtime/wr_runtime/control/run_policy.py --bundle training/checkpoints/standing_v0.12.2 --log-path signa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
    [robot_io.py, run_policy.py]
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2026-02-27 fix the calibrate.py and mirror for shoulder_pitch/roll
    [finger.stl, finger_00000.stl, finger_00001.stl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]
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2026-02-28 convert the collision mesh to primitive part for better training performance
    [finger.stl, forearm.stl, heel_btm.stl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]
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2026-04-19 v0.20.1 cleanup: delete v1/v2-bound consumer code
    Round-3 reviewer correctly flagged that the 0ffc473 deletion left a
    wider stale-import surface than I scoped. ``import
    training.envs.wildrobot_env`` failed with ModuleNotFoundError on
    ``locomotion_contract``; the env was the visible breakage but
    control/kinematics/interfaces.py and several other files also
    imported the deleted modules.
    This commit makes the branch import-clean for everything EXCEPT
    ``training/envs/wildrobot_env.py`` itself, which stays known-broken
    until the v3-only rewrite next session. No file outside the env
    references any deleted symbol after this commit.
    DELETED:
    runtime/wr_runtime/control/loc_ref_runtime.py (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
    [run_policy.py]
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2026-05-04 v2 model: add ankle_roll joints + refactor asset pipeline
    Hardware change
    - Onshape model now has left/right ankle_roll joints (5 DoF per leg,
    was 4 DoF). Adds servo_bracket_top intermediate body between
    lower_leg and foot.
    - Foot bodies now named left_foot/right_foot directly in the export
    (no longer need post_process to rename foot/foot_2).
    Pipeline (assets/update_xml.sh)
    - No longer invokes onshape-to-robot. Reads from assets/v2/onshape_export/
    (staged manually before each pipeline run); rsyncs wildrobot.xml +
    meshes (with --delete) into assets/v2/.
    - Removed --export-onshape flag and v1 variant support.
    post_process.py
    - New inject_additional_xml: splices sensors.xml + joints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
    [finger.stl, foot_main.stl, foot_side.stl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]
2026-05-04 v2 model: tighten waist spawn z 0.5 -> 0.48 m
    ensure_root_body_pose now sets the keyframe-less spawn pose ~9 mm above
    the home keyframe equilibrium (pelvis_z = 0.4714 m), down from the
    previous ~29 mm buffer. Removes a visible drop on spawn for tools that
    load the model without first applying the home keyframe (most consumers
    do apply it; this only affects bare mj_forward without resetDataKeyframe
    and similar visualizations).
    Comment in the function documents the equilibrium reference and notes to
    re-tune if a future kinematic change shifts the home equilibrium by more
    than ~5 mm.
    [wildrobot.xml]
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2026-05-09 assets: rename inner-leg/arm bodies to canonical left_*/right_* in post_process
    Raw Onshape exports ship with two inconsistent body-name conventions
    in the same model: inner-leg bodies (`upper_leg`, `lower_leg`,
    `servo_bracket_top`) are plain on the LEFT side and `_2`-suffixed on
    the RIGHT, while arm bodies (`shoulder`, `upper_arm`, `fore_arm`,
    `palm`, `finger`) are plain on the RIGHT and `_2`-suffixed on the LEFT
    (inverted). Hip and foot bodies are already `left_*`/`right_*` in
    the source. This was a maintenance hazard, not a correctness issue
    (PPO/planner reference joints by name, not bodies), but worth fixing
    to make the model self-consistent.
    - assets/post_process.py: new `rena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
    [wildrobot.xml]
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2026-05-17 assets: replace finger mesh collision with OBB-derived capsule proxy
    The raw finger.stl has a coplanar face with >20 vertices that trips
    MJX's convex-hull quality warning and pays real narrow-phase cost on
    collisions that don't matter for flat-ground locomotion (ToddlerBot's
    walking scenes don't model finger collision at all; hand collisions
    only appear in climb/crawl scenes). Replace the 4 finger collision
    meshes with capsule primitives that wrap each finger's volume, keeping
    "fingertip can touch something" semantics for future grasping work.
    - assets/post_process.py:
    * Factor out `_replace_collision_with_capsule(xml, mesh_filter)` from
    the existing `replace_upper_leg_coll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
    [wildrobot.xml]
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2026-06-06 runtime: v0.21.0 smoke9 hardware runner (wr_obs_v8_cmd3d home-residual)
    Make the runtime actually run the latest smoke9 walking bundles, not just
    export/validate them.
    Export (training side):
    - New training/exports/runtime_metadata.py freezes the control contract the
    runtime needs but policy_spec.json does not carry: residual base/scale/
    per-joint (resolved into actuator order), action_delay_steps,
    action_filter_alpha, 3D command axes, default eval cmd, and the gait phase
    clock. The phase clock is built from the offline ZMP library and verified
    bin-independent (max diff 0.0 across 40 bins), so a single shared
    phase_sin/phase_cos array + per-bin n_steps + cmd_keys is exact.
    - exp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
    [mock_robot_io.py, policy_runner.py, reference_phase.py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]
2026-06-06 runtime: fix hardware-mode startup + enforce action dims (review)
    High: hardware mode could not start. _build_hardware_robot_io called
    Actuators.from_config / Imu.from_config / FootSwitches.from_config, which do not
    exist (those are Protocols; concrete classes are HiwonderBoardActuators /
    BNO085IMU / FootSwitches with direct constructors). Real-robot execution raised
    AttributeError before the first control tick. Now wires the concrete classes
    from WrRuntimeConfig (servo ids/offsets/signs/center, IMU i2c/axis_map,
    footswitch pins), defaulting move_time_ms to one control period when the config
    omits it (HardwareRobotIO.write_ctrl passes move_time_ms=None).
    Medium: wildrobot-run-policy did n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
    [policy_runner.py, run_policy.py]
2026-06-06 runtime: add ankle_roll servos to runtime config + fail-fast on missing servos (review)
    High: hardware mode still failed for the 21-actuator v8 smoke9 spec because
    runtime_config_template.json (copied verbatim into every exported bundle) only
    defined 19 servos, omitting left_ankle_roll / right_ankle_roll. The v8 robot
    config includes both, and HiwonderBoardActuators raises on a missing servo ID,
    so startup hit KeyError "Servo ID missing for joint 'left_ankle_roll'".
    - Add left_ankle_roll (id 9) and right_ankle_roll (id 10) to
    runtime_config_template.json and runtime_config_v2.json (sign -1, offset 0 —
    placeholder IDs continuing the 1-8 leg block; offsets to be calibrated).
    Verified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
    [run_policy.py]
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2026-06-26 Include preflight errors in runtime failure
    [run_policy.py]
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2026-06-27 Tighten BNO startup readiness checks
    [robot_io.py]
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2026-07-04 Skip unchanged TTL servo writes
    [actuators.py, run_policy.py, servo_io_worker.py]
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2026-07-06 Fix walking ONNX activation parity
    [policy_runner.py, run_policy.py]
2026-07-08 Prevent servo feedback starvation during writes
    [run_policy.py, servo_io_worker.py]
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2026-07-18 Add startup home stability gate
    [run_policy.py]
2026-07-18 Loosen startup stability tilt limit
    Raise startup home tilt allowance to 15 degrees and expose a runtime CLI override.
    [run_policy.py]
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2026-07-27 training: fix simulation quaternion contract
    [run_policy.py]
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2026-08-31 fix standing trial handoff
    [run_policy.py]
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2026-09-10 runtime: allow bounded startup pose correction
    [run_policy.py]
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
